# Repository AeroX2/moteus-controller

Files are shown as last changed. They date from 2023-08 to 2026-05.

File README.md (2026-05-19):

# moteus-controller

A custom servo BLDC driver loosely based on the [mjbots Moteus r4.11](https://github.com/mjbots/moteus/tree/main/hw/controller/r4.11) hardware.

Main differences from upstream Moteus r4.11:

- **STSPIN32G4** integrated gate driver + STM32G431 instead of separate DRV8353S and MCU.
- Schematic and BOM trimmed/substituted for **JLCPCB** assembly.
- **AS5048A** magnetic encoder.
- **MAX3051** CAN transceiver.
- Firmware built on **SimpleFOC** + Arduino-stm32duino instead of the mjbots firmware.

## Repository layout

```
moteus-controller/
├── pcb/                # KiCad schematic + PCB
├── firmware/           # SimpleFOC-based motor controller firmware (PlatformIO + Arduino)
├── bootloader/         # OpenBLT bootloader for STM32G431VB  (submodule -> AeroX2/OpenBLT-STM32)
└── openblt/            # OpenBLT library + mjbots fdcanusb driver (submodule -> AeroX2/openblt)
```

`firmware/`, `bootloader/`, and `openblt/` each have their own build setup and README.

## Quick build / flash

Prerequisites: [PlatformIO Core](https://platformio.org/install/cli), an ST-Link, optionally a [mjbots fdcanusb](https://github.com/mjbots/fdcanusb) for CAN-FD uploads.

Clone with submodules:

```bash
git clone --recurse-submodules https://github.com/AeroX2/moteus-controller.git
cd moteus-controller
```

Flash the bootloader once (writes at `0x08000000`, ~8 KB):

```bash
pio run -d bootloader -e moteus_g431 -t upload
```

Flash the application (writes at `0x08005000`):

```bash
pio run -d firmware -e moteus -t upload
```

Power-cycle the board; the bootloader runs for ~3 s, then jumps to the app.

After the bootloader is in place, subsequent firmware uploads can go over CAN-FD via fdcanusb (no ST-Link needed):

```bash
pio run -d firmware -e moteus_openblt_can -t upload
```

## Bootloader

`bootloader/` is a bare-metal **stm32cube + PlatformIO** port of the upstream [Feaser OpenBLT](https://github.com/feaser/openblt) Nucleo-G431 demo, adapted for the moteus-controller hardware:

- HSI → PLL → 170 MHz (no HSE crystal on this board).
- FDCAN1 routed to PA11/PA12 (vs Nucleo's PB8/PB9).
- 20 KB reserved at `0x08000000`; app starts at `0x08005000`; the final 2 KB flash page (`0x0801F800`) is reserved for application PID storage and never touched by the bootloader.

OpenBLT library + STM32G4 port sources are compiled directly from the `openblt/` submodule by `bootloader/src/build.py` — there are no local copies of those files in `bootloader/`, so updating to a newer OpenBLT is just a submodule bump.

## CAN-FD upload (`moteus_openblt_can` env)

The CAN-FD upload path uses a custom **mjbots fdcanusb** host driver added to LibOpenBLT (see `openblt/Host/Source/LibOpenBLT/port/windows/canif/fdcanusb/`) plus a small wrapper (`firmware/host_openblt_flash/`) and a Python harness (`firmware/scripts/openblt_host_upload.py`) that handles pre-reset, device discovery, and srec conversion.

Build the host tool once:

```bash
python firmware/scripts/build_host_openblt_flash.py
```

Then `pio run -d firmware -e moteus_openblt_can -t upload` does the rest.

Tuning knobs live in `firmware/platformio.ini` under `[env:moteus_openblt_can]`:

- `custom_openblt_can_device` — fdcanusb COM port and USB baud.
- `custom_openblt_can_tid` / `custom_openblt_can_rid` — XCP CAN IDs (default `667` / `7E1`, must match `bootloader/src/blt_conf.h`).
- `custom_openblt_reset_discover` / `custom_openblt_reset_target_id` — control how the running application is asked to reboot into the bootloader before uploading.

## License

The original mjbots Moteus design is licensed under Apache 2.0; see `LICENSE`. OpenBLT and its derivatives are GPLv3 (see `openblt/Doc/license.html`).

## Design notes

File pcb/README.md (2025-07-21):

# moteus-controller

## Schematic
schematic

## PCB
https://kicanvas.org/?github=https%3A%2F%2Fgithub.com%2FAeroX2%2Fmoteus-controller%2Ftree%2Fmain%2Fpcb

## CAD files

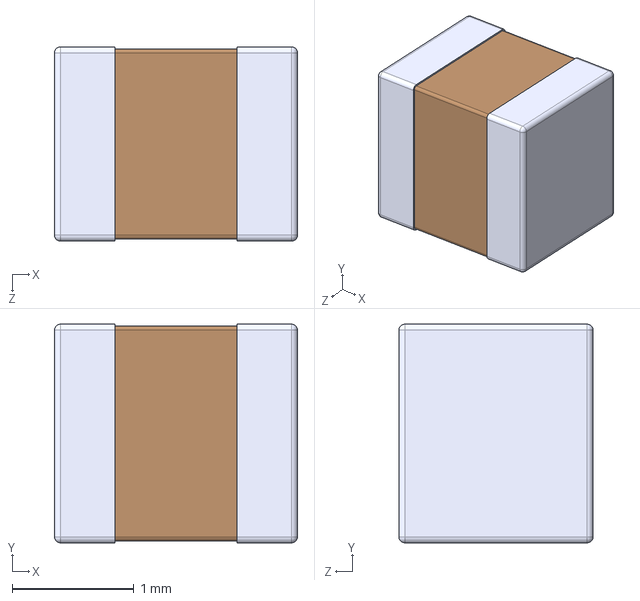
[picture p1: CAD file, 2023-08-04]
pcb/LBM2016T120J.step
2.00 x 1.80 x 1.60 mm

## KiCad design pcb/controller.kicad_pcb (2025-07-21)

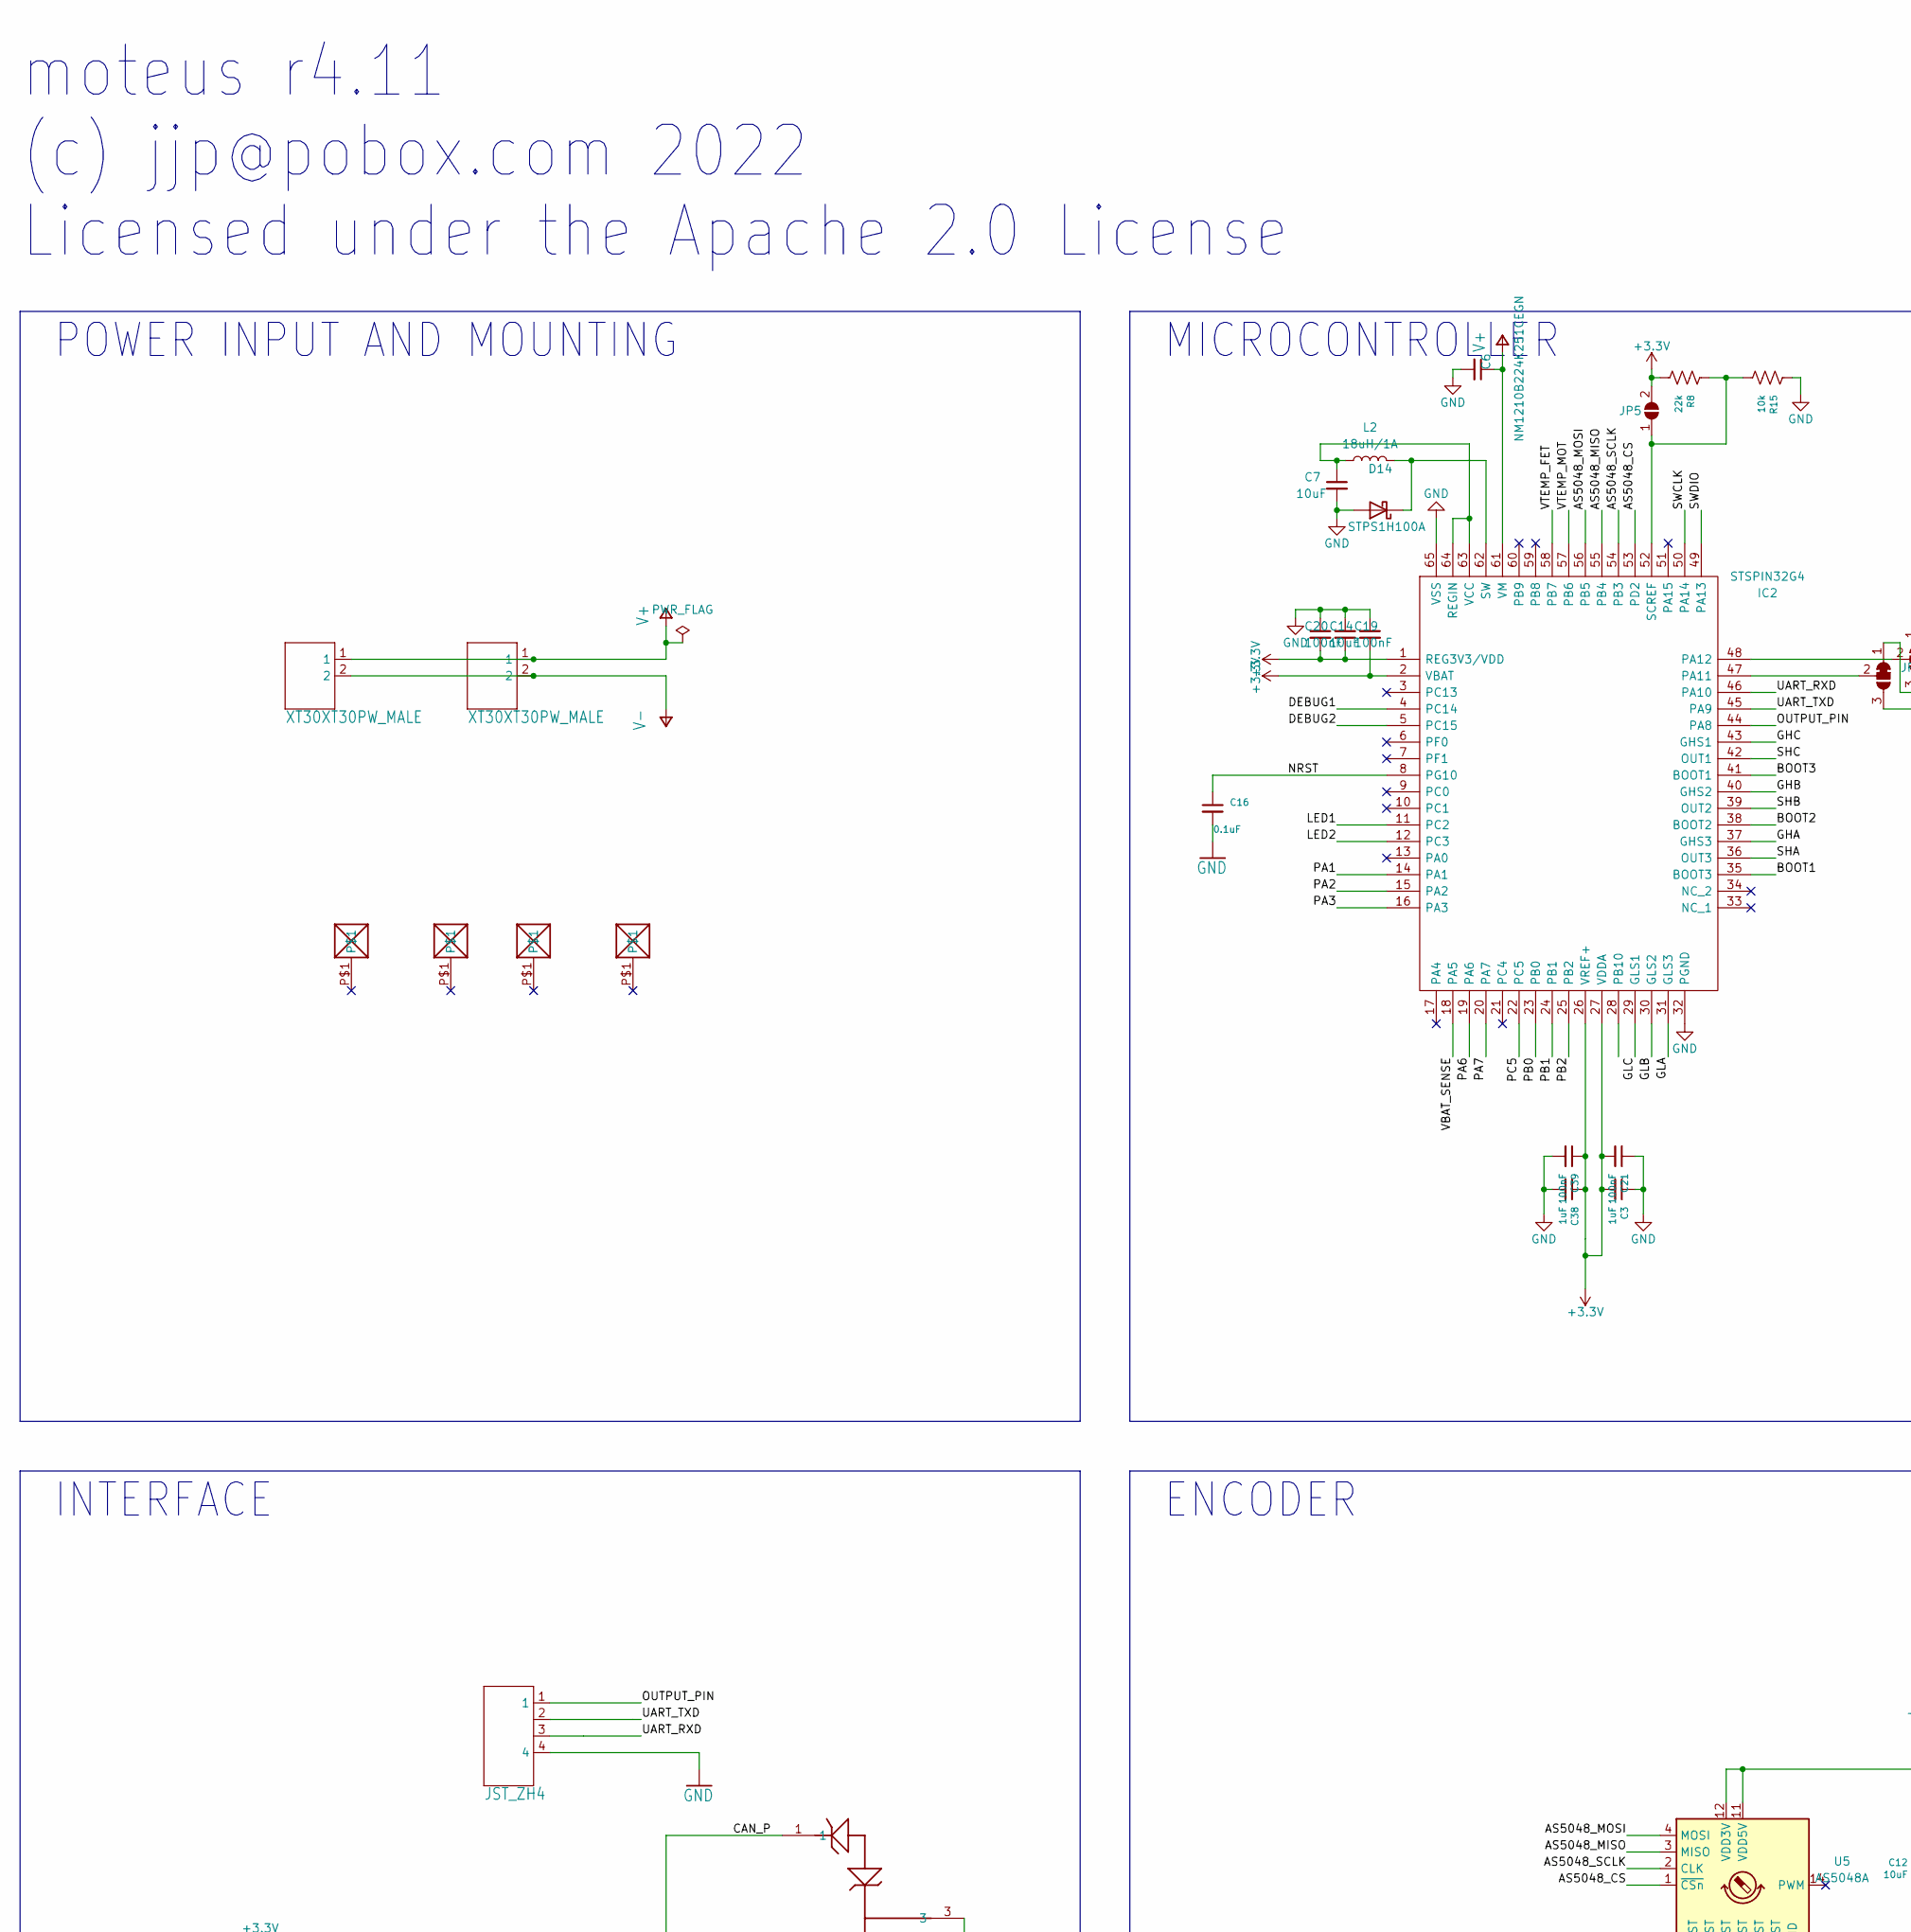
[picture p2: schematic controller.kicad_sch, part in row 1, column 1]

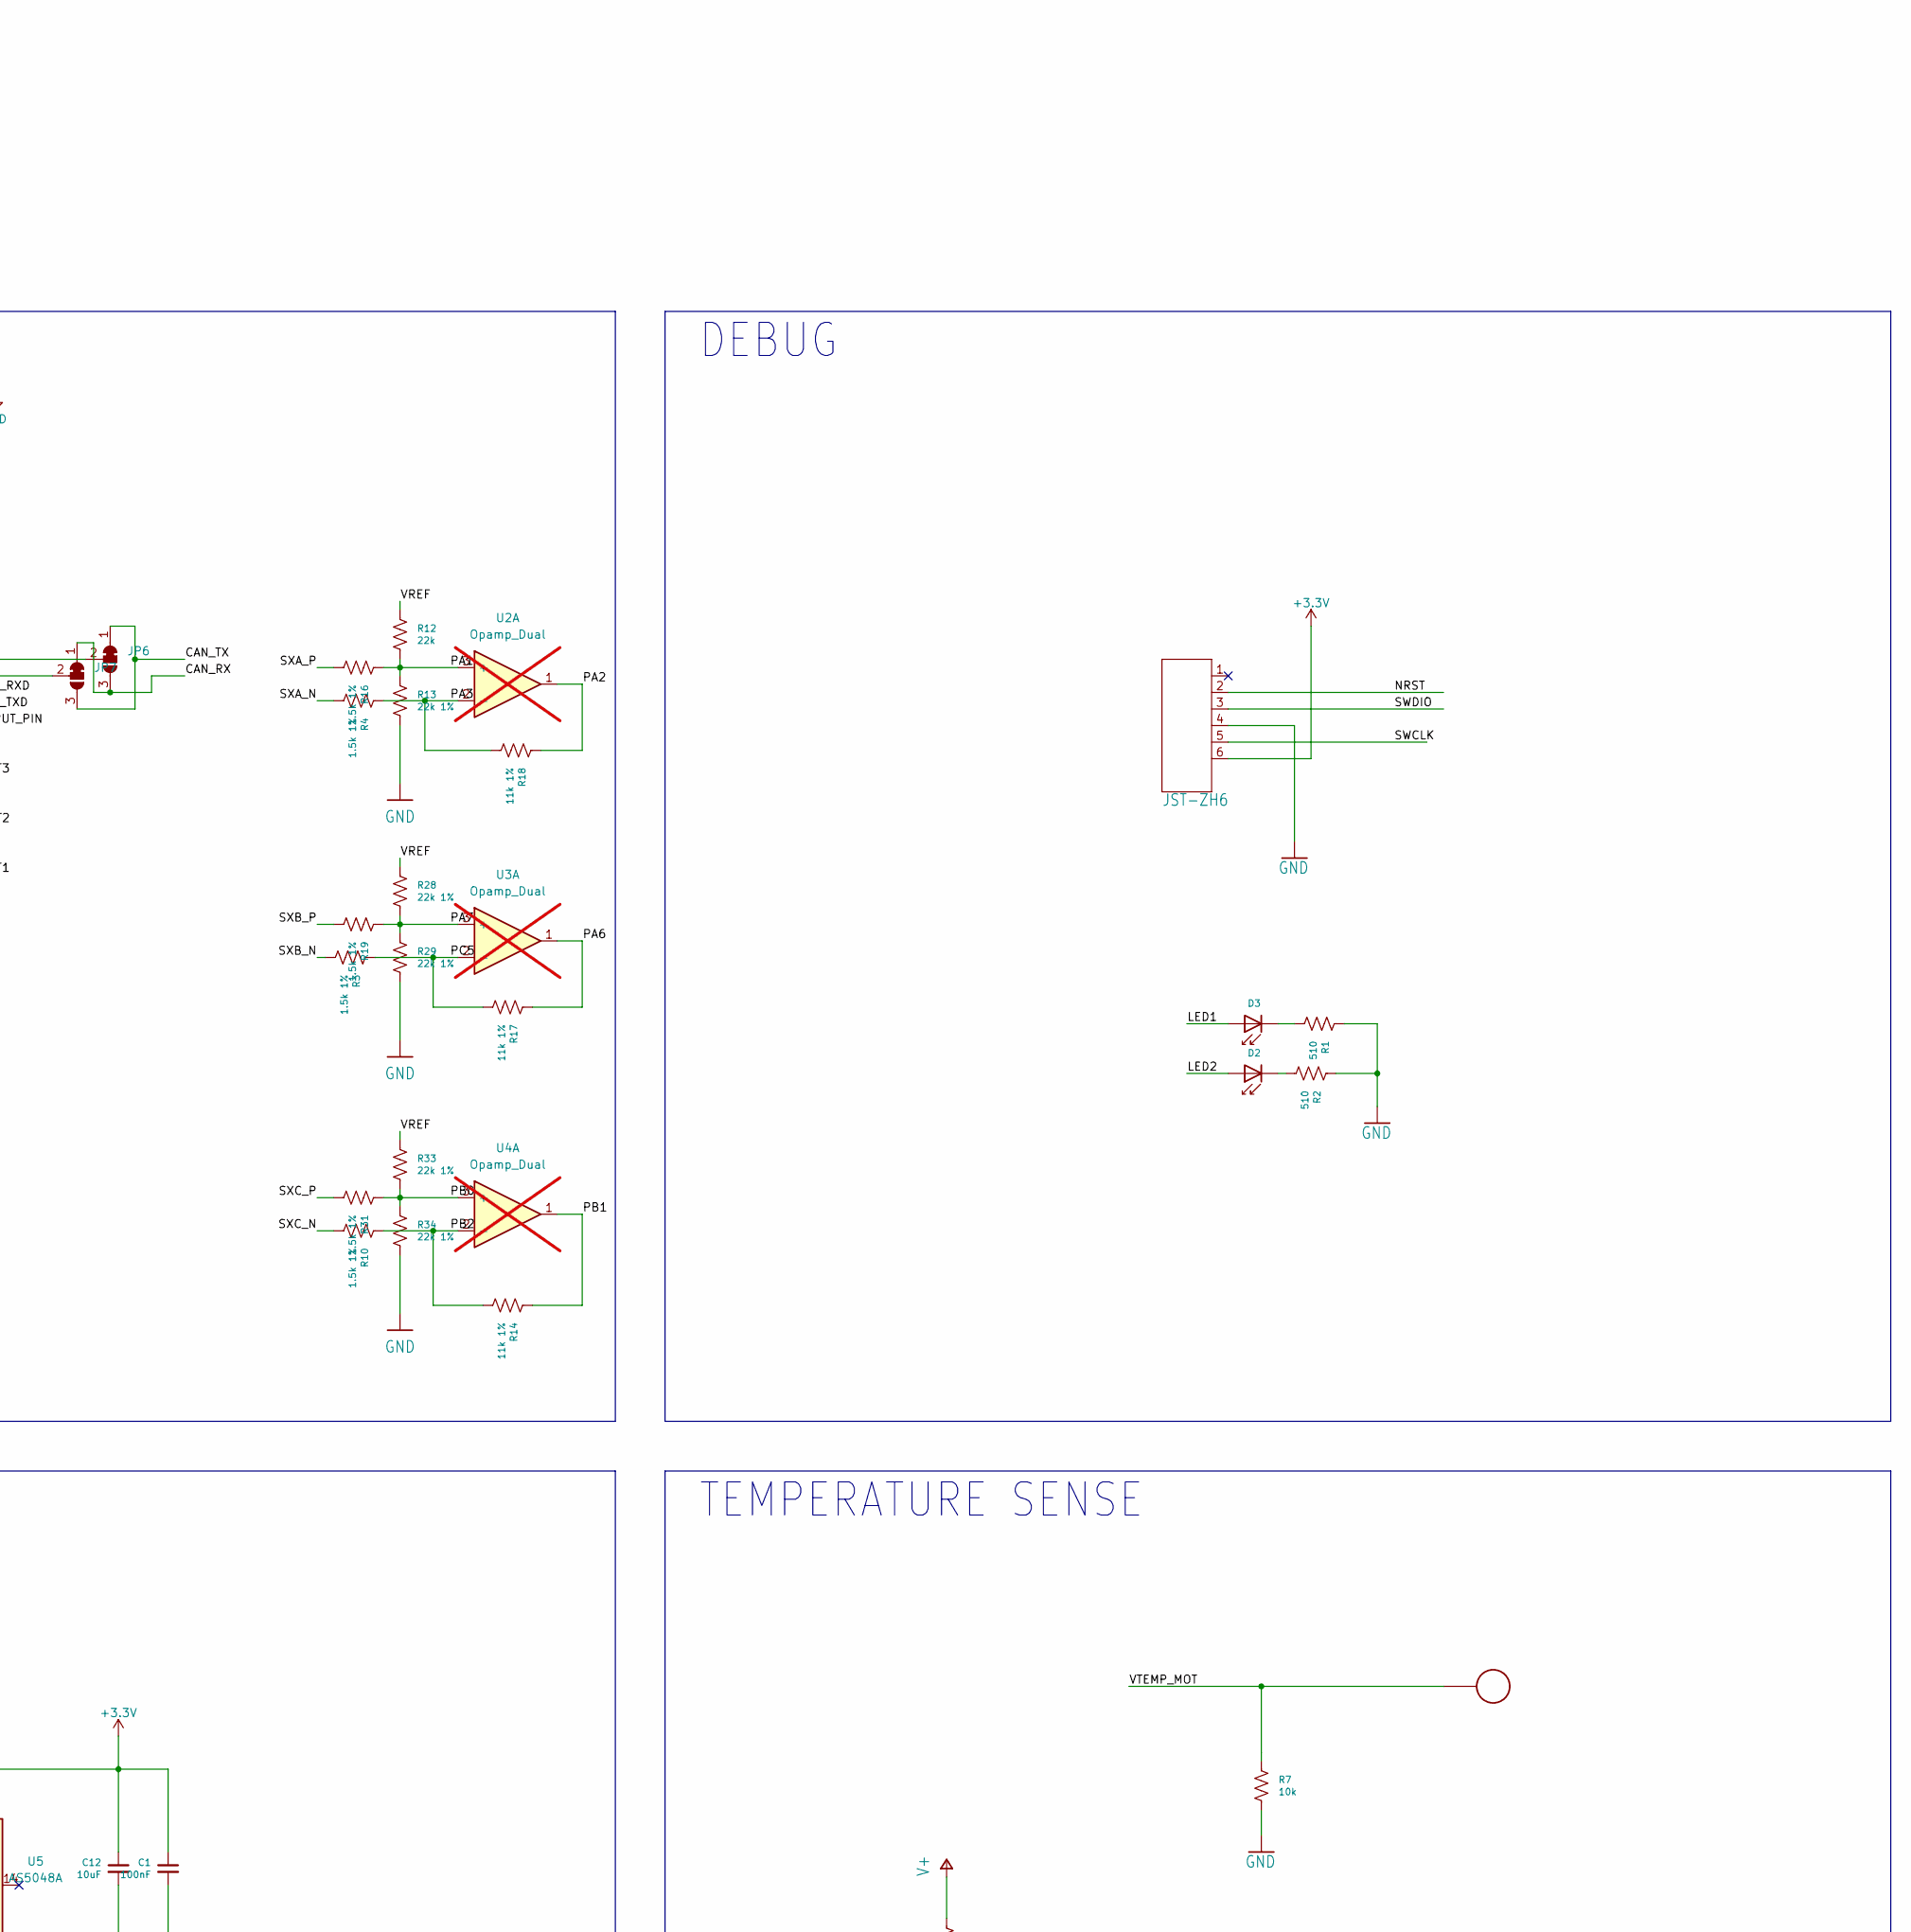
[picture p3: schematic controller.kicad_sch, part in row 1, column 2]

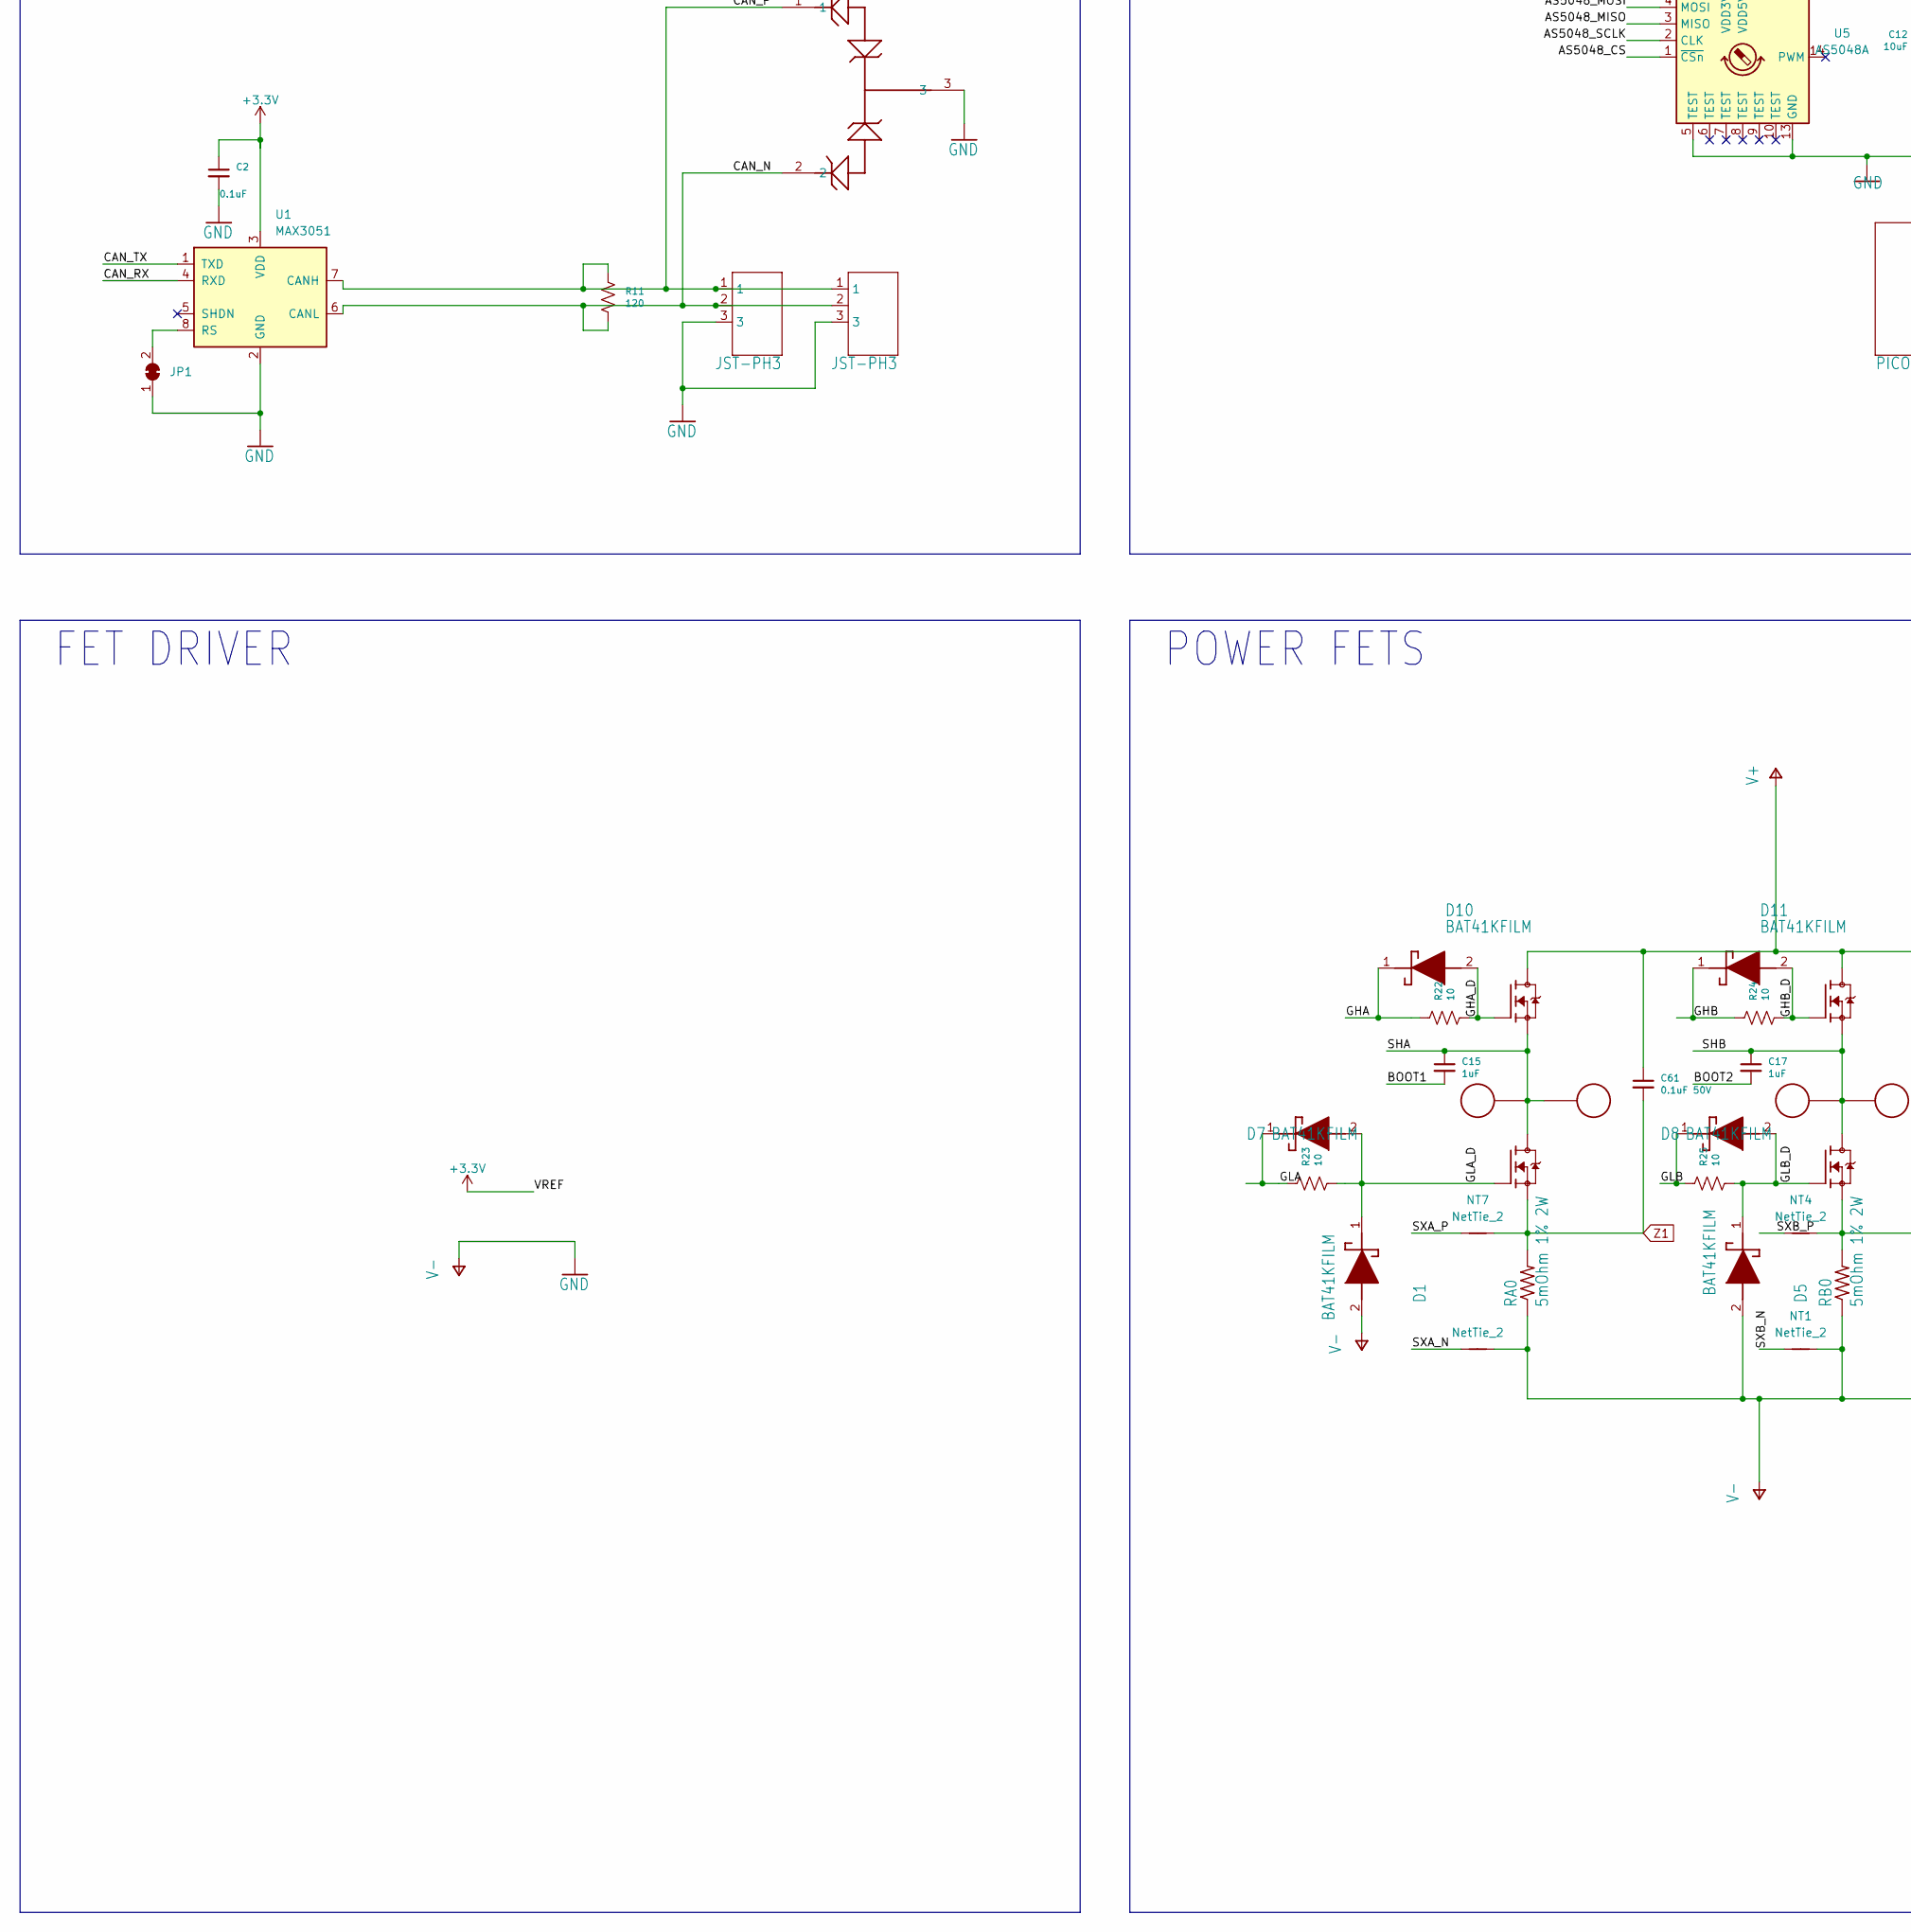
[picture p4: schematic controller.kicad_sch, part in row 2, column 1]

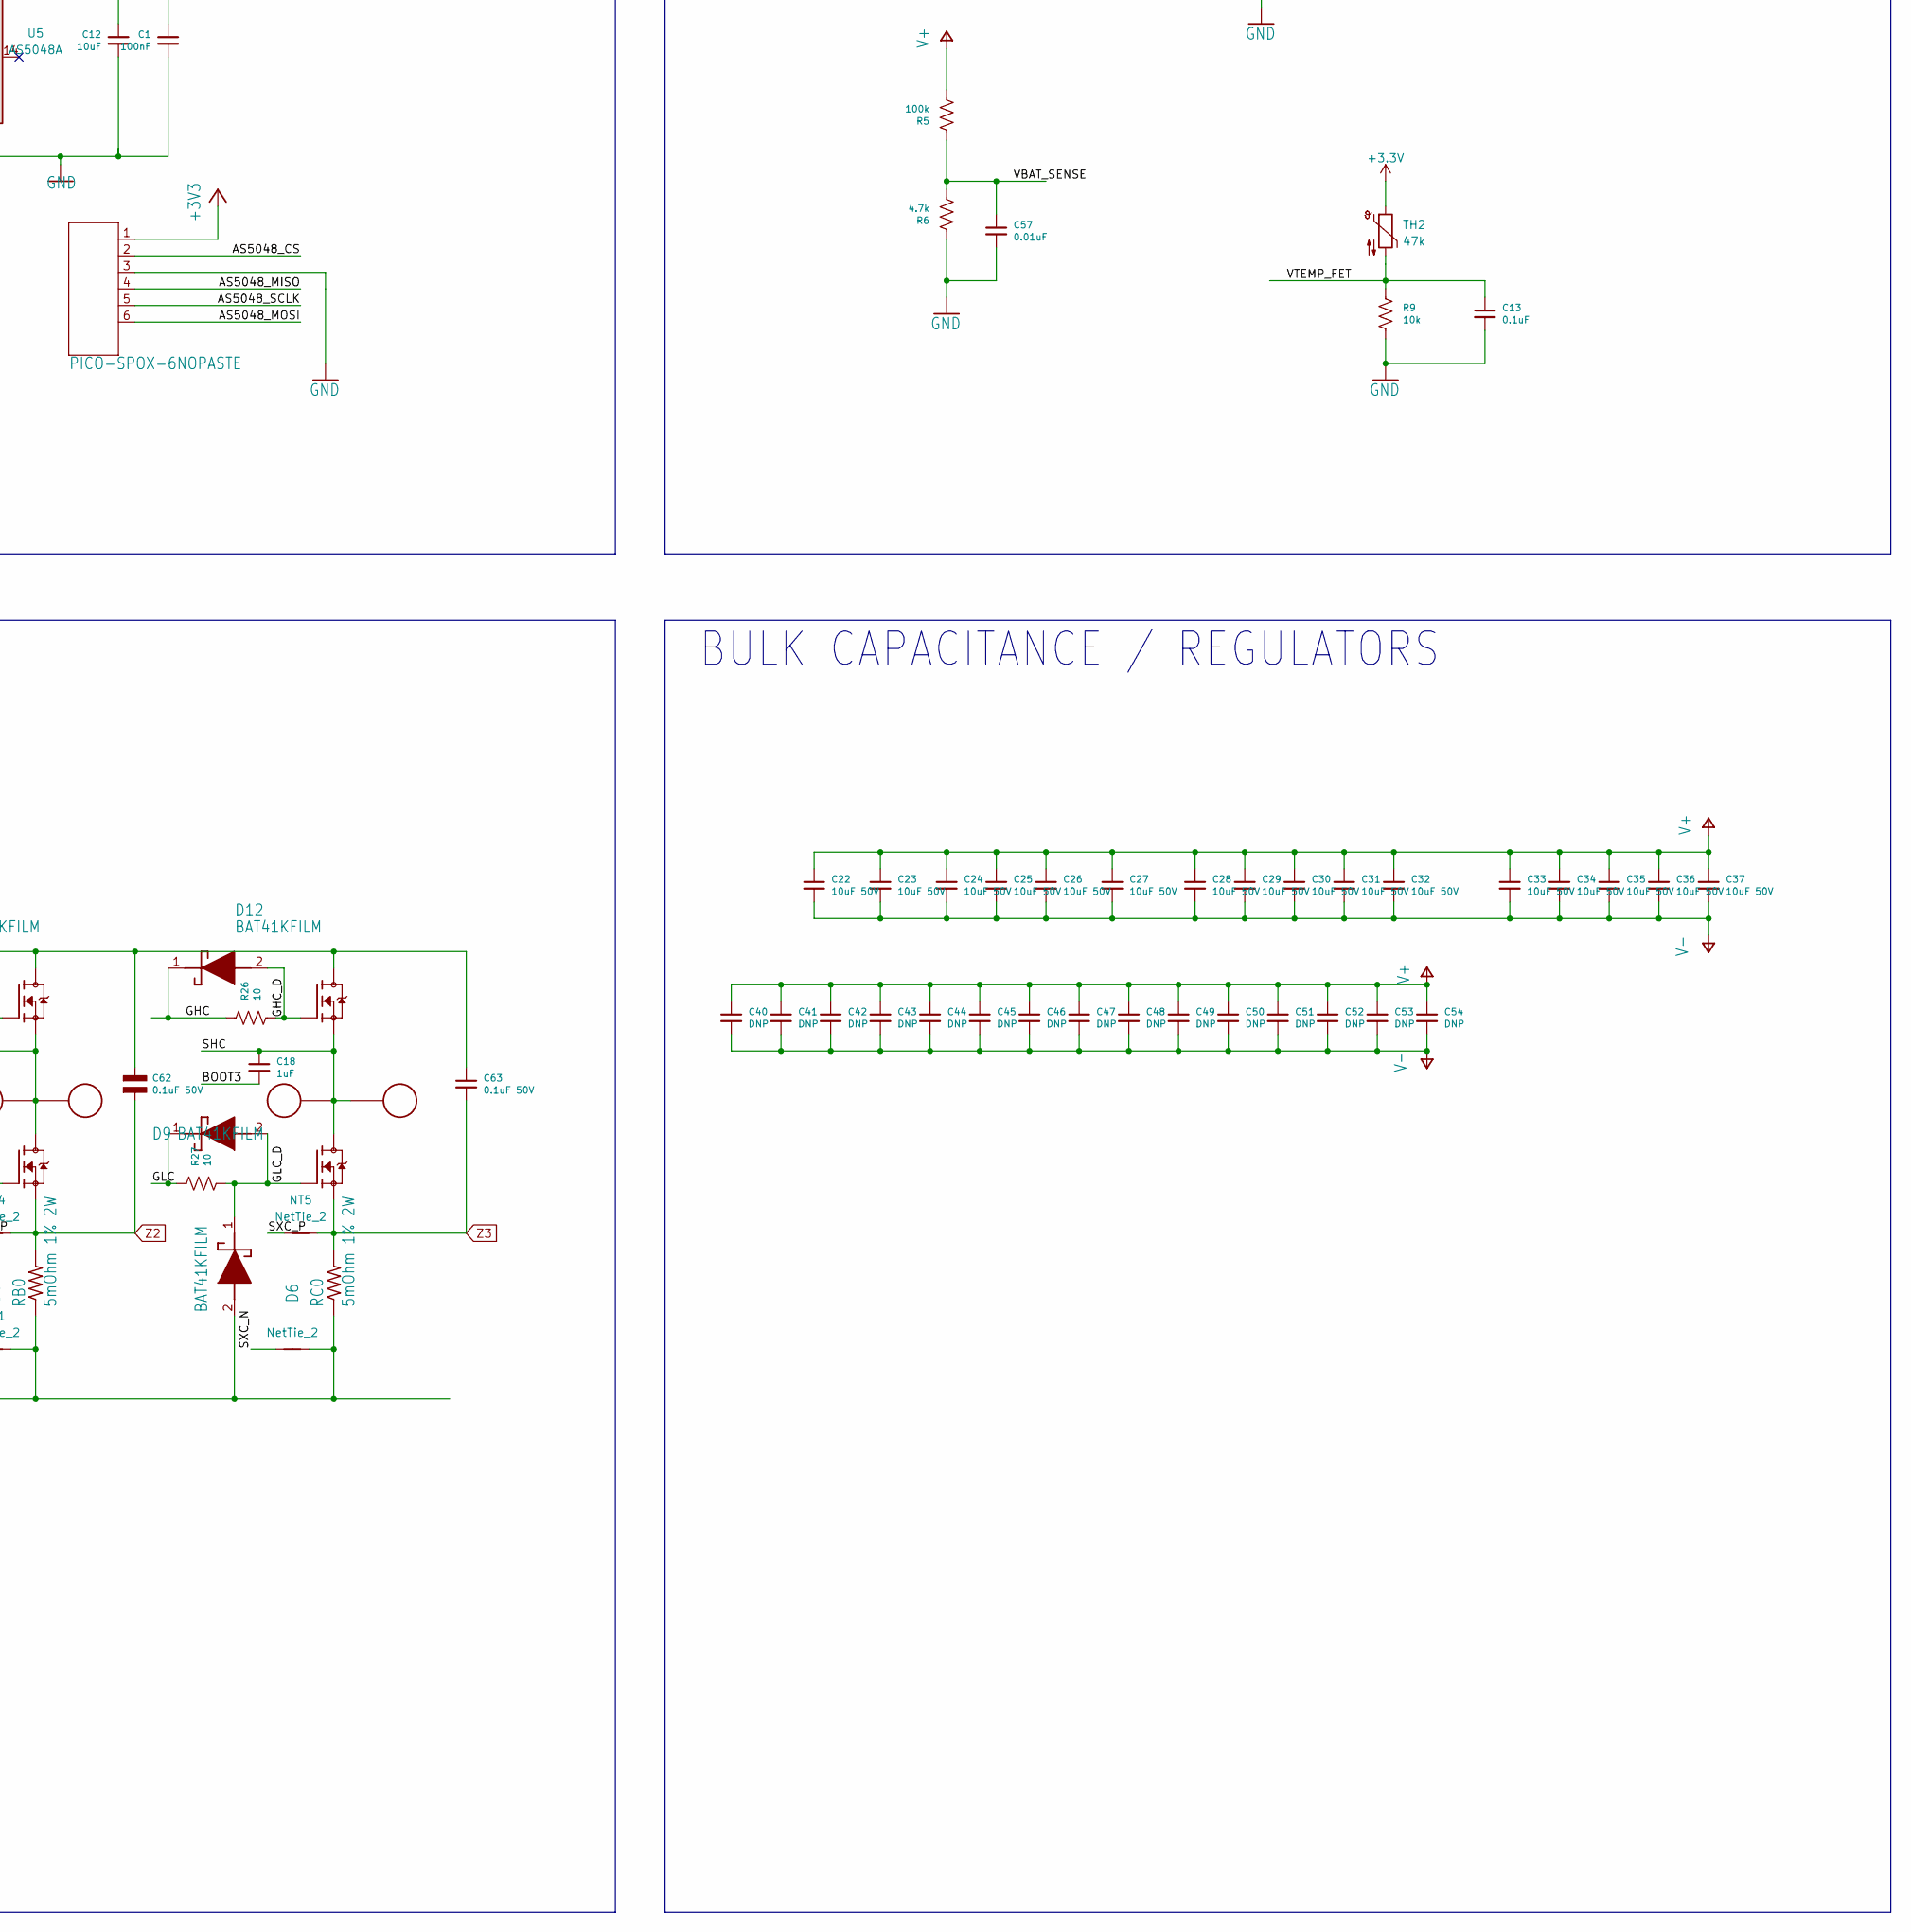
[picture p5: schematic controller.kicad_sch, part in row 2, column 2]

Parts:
A0: PAD16AWG_PAD; 16AWG_PAD
ABS0: JST_ZH4; JST_S4B-ZR-SM4A-TF(LF)(SN); MPN S4B-ZR-SM4A-TF(LF)(SN)
B0: PAD16AWG_PAD; 16AWG_PAD
C0: PAD16AWG_PAD; 16AWG_PAD
C1: 100nF; C_0402_1005Metric; MPN MF-CAP-0402-0.1uF
C2, C13, C16: 0.1uF; C_0402_1005Metric; MPN MF-CAP-0402-0.1uF
C3, C15, C17, C18, C38: 1uF; C_0402_1005Metric; MPN MF-CAP-0402-1uF
C6: NM1210B224K251CEGN; C_1210_3225Metric
C7, C14: 10uF; C_0402_1005Metric
C12: 10uF; C_0402_1005Metric; MPN MF-CAP-0402-0.1uF
C19, C20: 100nF; C_0402_1005Metric
C21, C39: 100nF; C_0402_1005Metric; MPN MF-CAP-0402-1uF
C22, C23, C24, C25, C26, C27, C28, C29, C30, C31, C32, C33, C34, C35, C36, C37: 10uF 50V; C_1206_3216Metric; MPN C3216X7R1H106K160AE
C40, C41, C42, C43, C44, C45, C46, C47, C48, C49, C50, C51, C52, C53, C54: DNP; C_1206_3216Metric
C57: 0.01uF; C_0402_1005Metric; MPN MF-CAP-0402-0.01uF
C61, C63: 0.1uF 50V; C_1206_3216Metric; MPN 12065C104KAZ2A
C62: 0.1uF 50V; C0603_NOBORDER; MPN 06035C104KAZ2A
CAN1, CAN2: JST-PH3; JST_S3B-PH-SM4-TB(LF)(SN); MPN S3B-PH-SM4-TB(LF)(SN)
D1, D5, D6, D7, D8, D9, D10, D11, D12: BAT41KFILM; SODFL1608X70N; MPN BAT41KFILM
D2: MF-LED-0603-RED; LED_0603_1608Metric; MPN MF-LED-0603-GREEN
D3: MF-LED-0603-RED; LED_0603_1608Metric
D4: DUAL_TVS; SOT23-3; MPN CDSOT23-0502B
D14: STPS1H100A; D_SMA
DA0: PAD24AWG_PAD; 24AWG_PAD
DB0: PAD24AWG_PAD; 24AWG_PAD
DC0: PAD24AWG_PAD; 24AWG_PAD
ENC0: PICO-SPOX-6NOPASTE; PICO-SPOX-SMT-RA-6-NOPASTE
IC2: STSPIN32G4; QFN50P900X900X100-65N-D; Manufacturer_Part_Number STSPIN32G4; Mouser Part Number 511-STSPIN32G4
J1, J2: XT30XT30PW_MALE; XT30PW_MALE
JP1: SolderJumper_2_Bridged; SolderJumper-2_P1.3mm_Bridged_Pad1.0x1.5mm
JP5: SolderJumper_2_Open; SolderJumper-2_P1.3mm_Open_RoundedPad1.0x1.5mm
JP6, JP7: SolderJumper_3_Bridged12; SolderJumper-3_P1.3mm_Bridged12_RoundedPad1.0x1.5mm
L2: 18uH/1A; IND-SMD_L5.8-W5.2_SCD0503T
M1, M2, M3, M4: MOUNT; MountingHole_3.2mm_M3_DIN965_Pad
NT1, NT4, NT5, NT6, NT7, NT8: NetTie_2; NetTie-2_SMD_Pad0.2mm
Q1, Q3, Q5: TPH1R204PLSOP_ADVANCE_8; SOP_ADVANCE_8; MPN TPH2R506PL,L1Q
Q2, Q4, Q6: TPH1R204PLSOP_ADVANCE_8; SOP_ADVANCE_8; MPN TPH4R50ANH,L1Q(M
R1, R2: 510; R_0402_1005Metric; MPN MF-RES-0402-560
R3, R4, R10, R16, R19, R31: 1.5k 1%; R_0402_1005Metric; MPN MF-RES-0402-2K
R5: 100k; R_0402_1005Metric; MPN RC0402FR-07100KL
R6: 4.7k; R_0402_1005Metric; MPN RC0402FR-074K7L
R7, R9: 10k; R_0402_1005Metric; MPN RC0402FR-0710KL
R8, R12: 22k; R_0402_1005Metric; MPN MF-RES-0402-2K
R11: 120; R_0402_1005Metric; MPN MF-RES-0402-2K
R13, R28, R29, R33, R34: 22k 1%; R_0402_1005Metric; MPN MF-RES-0402-2K
R14, R17, R18: 11k 1%; R_0402_1005Metric; MPN MF-RES-0402-2K
R15: 10k; R_0402_1005Metric; MPN MF-RES-0402-2K
R22, R23, R24, R25, R26, R27: 10; R_0402_1005Metric; MPN RC0402FR-077R5L
RA0: 5mOhm 1% 2W; R_1206_3216Metric; MPN HCS1206FTL500
RB0: 5mOhm 1% 2W; R_1206_3216Metric; MPN HCS1206FTL500
RC0: 5mOhm 1% 2W; R_1206_3216Metric; MPN HCS1206FTL500
SWD0: JST-ZH6; JST_S6B-ZR-SM4A-TF(LF)(SN); MPN S6B-ZR-SM4A-TF(LF)(SN)
TEMP2: PAD24AWG_PAD; 24AWG_PAD
TH2: 47k; R_0603_1608Metric
U1: MAX3051; TSOT-23-8
U2, U3, U4: Opamp_Dual; not fitted
U5: AS5048A; TSSOP-14_4.4x5mm_P0.65mm

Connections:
+3.3V: C1.1, C2.1, C3.2, C12.1, C14.2, C19.2, C20.2, C21.2, C38.1, C39.1, IC2.1 (REG3V3/VDD), IC2.2 (VBAT), IC2.26 (VREF+), IC2.27 (VDDA), JP5.2 (B), R8.2, R12.1, R28.1, R33.1, SWD0.6, TH2.1, U1.3 (VDD), U5.11 (VDD5V), U5.12 (VDD3V)
+3V3: ENC0.1
/AS5048_CS: ENC0.2, IC2.53 (PD2), U5.1 (~CSn)
/AS5048_MISO: ENC0.4, IC2.55 (PB4), U5.3 (MISO)
/AS5048_MOSI: ENC0.6, IC2.56 (PB5), U5.4 (MOSI)
/AS5048_SCLK: ENC0.5, IC2.54 (PB3), U5.2 (CLK)
/BOOT1: C15.2, IC2.35 (BOOT3)
/BOOT2: C17.2, IC2.38 (BOOT2)
/BOOT3: C18.2, IC2.41 (BOOT1)
/CAN_N: CAN1.2, CAN2.2, D4.2, R11.2, U1.6 (CANL)
/CAN_P: CAN1.1, CAN2.1, D4.1, R11.1, U1.7 (CANH)
/CAN_RX: JP6.3 (B), JP7.1 (A), U1.4 (RXD)
/CAN_TX: JP6.1 (A), JP7.3 (B), U1.1 (TXD)
/DEBUG1: IC2.4 (PC14)
/DEBUG2: IC2.5 (PC15)
/GHA: D10.1 (K), IC2.37 (GHS3), R22.1
/GHA_D: D10.2 (A), Q1.4 (G), R22.2
/GHB: D11.1 (K), IC2.40 (GHS2), R24.1
/GHB_D: D11.2 (A), Q3.4 (G), R24.2
/GHC: D12.1 (K), IC2.43 (GHS1), R26.1
/GHC_D: D12.2 (A), Q5.4 (G), R26.2
/GLA: D7.1 (K), IC2.31 (GLS3), R23.1
/GLA_D: D1.1 (K), D7.2 (A), Q2.4 (G), R23.2
/GLB: D8.1 (K), IC2.30 (GLS2), R25.1
/GLB_D: D5.1 (K), D8.2 (A), Q4.4 (G), R25.2
/GLC: D9.1 (K), IC2.29 (GLS1), R27.1
/GLC_D: D6.1 (K), D9.2 (A), Q6.4 (G), R27.2
/LED1: D3.2 (A), IC2.11 (PC2)
/LED2: D2.2 (A), IC2.12 (PC3)
/NRST: C16.1, IC2.8 (PG10), SWD0.2
/OUTPUT_PIN: ABS0.1, IC2.44 (PA8)
/PA1: IC2.14 (PA1), R12.2, R13.1, R16.1, U2.3 (+)
/PA2: IC2.15 (PA2), R18.1, U2.1
/PA3: IC2.16 (PA3), R4.1, R18.2, U2.2 (-)
/PA6: IC2.19 (PA6), R17.1, U3.1
/PA7: IC2.20 (PA7), R19.1, R28.2, R29.1, U3.3 (+)
/PB0: IC2.23 (PB0), R31.1, R33.2, R34.1, U4.3 (+)
/PB1: IC2.24 (PB1), R14.1, U4.1
/PB2: IC2.25 (PB2), R10.1, R14.2, U4.2 (-)
/PC5: IC2.22 (PC5), R3.1, R17.2, U3.2 (-)
/SHA: A0.1, C15.1, DA0.P$1, IC2.36 (OUT3), Q1.1 (S), Q1.2 (S), Q1.3 (S), Q2.5 (D), Q2.6 (D), Q2.7 (D), Q2.8 (D), Q2.PAD (D)
/SHB: B0.1, C17.1, DB0.P$1, IC2.39 (OUT2), Q3.1 (S), Q3.2 (S), Q3.3 (S), Q4.5 (D), Q4.6 (D), Q4.7 (D), Q4.8 (D), Q4.PAD (D)
/SHC: C0.1, C18.1, DC0.P$1, IC2.42 (OUT1), Q5.1 (S), Q5.2 (S), Q5.3 (S), Q6.5 (D), Q6.6 (D), Q6.7 (D), Q6.8 (D), Q6.PAD (D)
/SWCLK: IC2.50 (PA14), SWD0.5
/SWDIO: IC2.49 (PA13), SWD0.3
/SXA_N: NT8.1, R4.2
/SXA_P: NT7.1, R16.2
/SXB_N: NT1.1, R3.2
/SXB_P: NT4.1, R19.2
/SXC_N: NT6.1, R10.2
/SXC_P: NT5.1, R31.2
/UART_RXD: ABS0.3, IC2.46 (PA10)
/UART_TXD: ABS0.2, IC2.45 (PA9)
/VBAT_SENSE: C57.1, IC2.18 (PA5), R5.1, R6.2
/VTEMP_FET: C13.1, IC2.58 (PB7), R9.1, TH2.2
/VTEMP_MOT: IC2.57 (PB6), R7.1, TEMP2.P$1
GND: ABS0.4, C1.2, C2.2, C3.1, C6.2, C7.2, C12.2, C13.2, C14.1, C16.2, C19.1, C20.1, C21.1, C22.2, C23.2, C24.2, C25.2, C26.2, C27.2, C28.2, C29.2, C30.2, C31.2, C32.2, C33.2, C34.2, C35.2, C36.2, C37.2, C38.2, C39.2, C40.2, C41.2, C42.2, C43.2, C44.2, C45.2, C46.2, C47.2, C48.2, C49.2, C50.2, C51.2, C52.2, C53.2, C54.2, C57.2, CAN1.3, CAN2.3, D1.2 (A), D4.3, D5.2 (A), D6.2 (A), D14.2 (A), ENC0.3, IC2.32 (PGND), IC2.65 (VSS), J1.2, J2.2, JP1.1 (A), NT1.2, NT6.2, NT8.2, R1.1, R2.1, R6.1, R7.2, R9.2, R13.2, R15.1, R29.2, R34.2, RA0.1, RB0.1, RC0.1, SWD0.4, U1.2 (GND), U5.5 (TEST), U5.13 (GND)
unnamed: D2.1 (K), R2.2
unnamed: D3.1 (K), R1.2
unnamed: D14.1 (K), IC2.62 (SW), L2.2
unnamed: IC2.47 (PA11), JP7.2 (C)
unnamed: IC2.48 (PA12), JP6.2 (C)
unnamed: C7.1, IC2.63 (VCC), IC2.64 (REGIN), L2.1
unnamed: IC2.52 (SCREF), JP5.1 (A), R8.1, R15.2
unnamed: JP1.2 (B), U1.8 (RS)
V+: C6.1, C22.1, C23.1, C24.1, C25.1, C26.1, C27.1, C28.1, C29.1, C30.1, C31.1, C32.1, C33.1, C34.1, C35.1, C36.1, C37.1, C40.1, C41.1, C42.1, C43.1, C44.1, C45.1, C46.1, C47.1, C48.1, C49.1, C50.1, C51.1, C52.1, C53.1, C54.1, C61.1, C62.P$1, C63.1, IC2.61 (VM), J1.1, J2.1, Q1.5 (D), Q1.6 (D), Q1.7 (D), Q1.8 (D), Q1.PAD (D), Q3.5 (D), Q3.6 (D), Q3.7 (D), Q3.8 (D), Q3.PAD (D), Q5.5 (D), Q5.6 (D), Q5.7 (D), Q5.8 (D), Q5.PAD (D), R5.2
Z1: C61.2, NT7.2, Q2.1 (S), Q2.2 (S), Q2.3 (S), RA0.2
Z2: C62.P$2, NT4.2, Q4.1 (S), Q4.2 (S), Q4.3 (S), RB0.2
Z3: C63.2, NT5.2, Q6.1 (S), Q6.2 (S), Q6.3 (S), RC0.2

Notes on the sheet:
DEBUG
POWER FETS
moteus r4.11 (c) jjp@pobox.com 2022 Licensed under the Apache 2.0 License
ENCODER
BULK CAPACITANCE / REGULATORS
INTERFACE
MICROCONTROLLER
FET DRIVER
TEMPERATURE SENSE
POWER INPUT AND MOUNTING

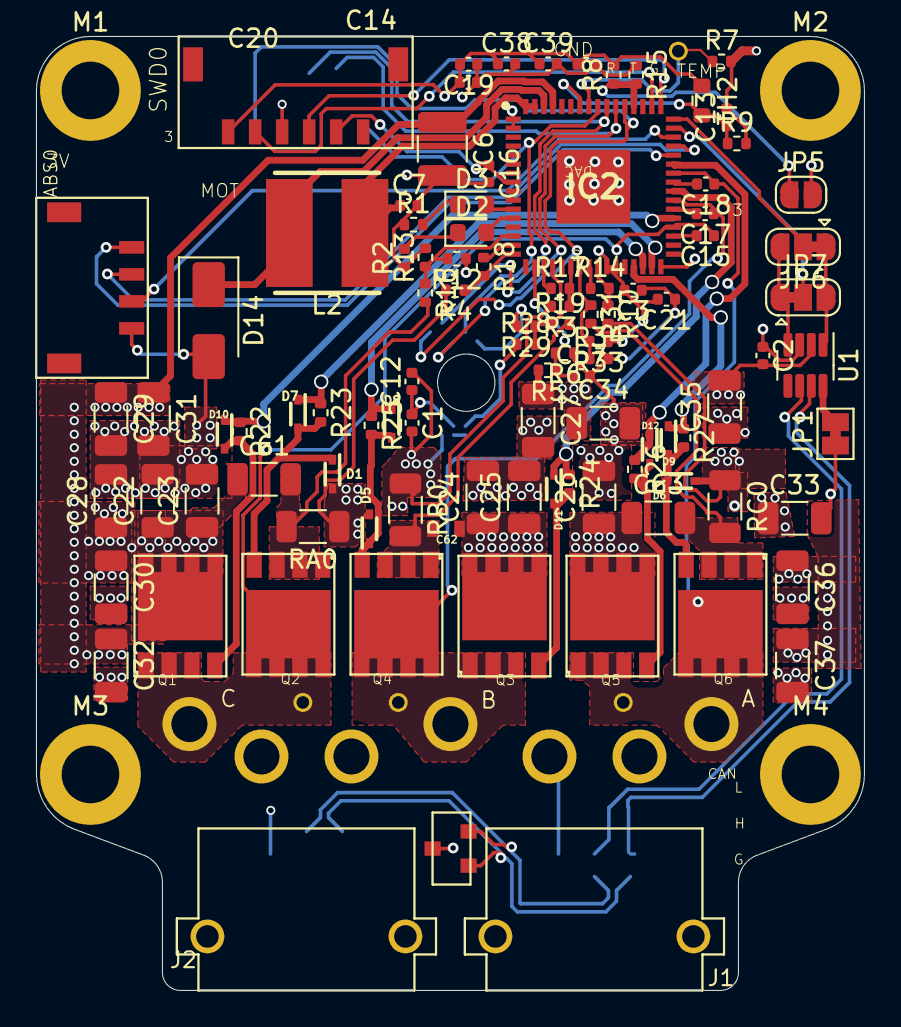
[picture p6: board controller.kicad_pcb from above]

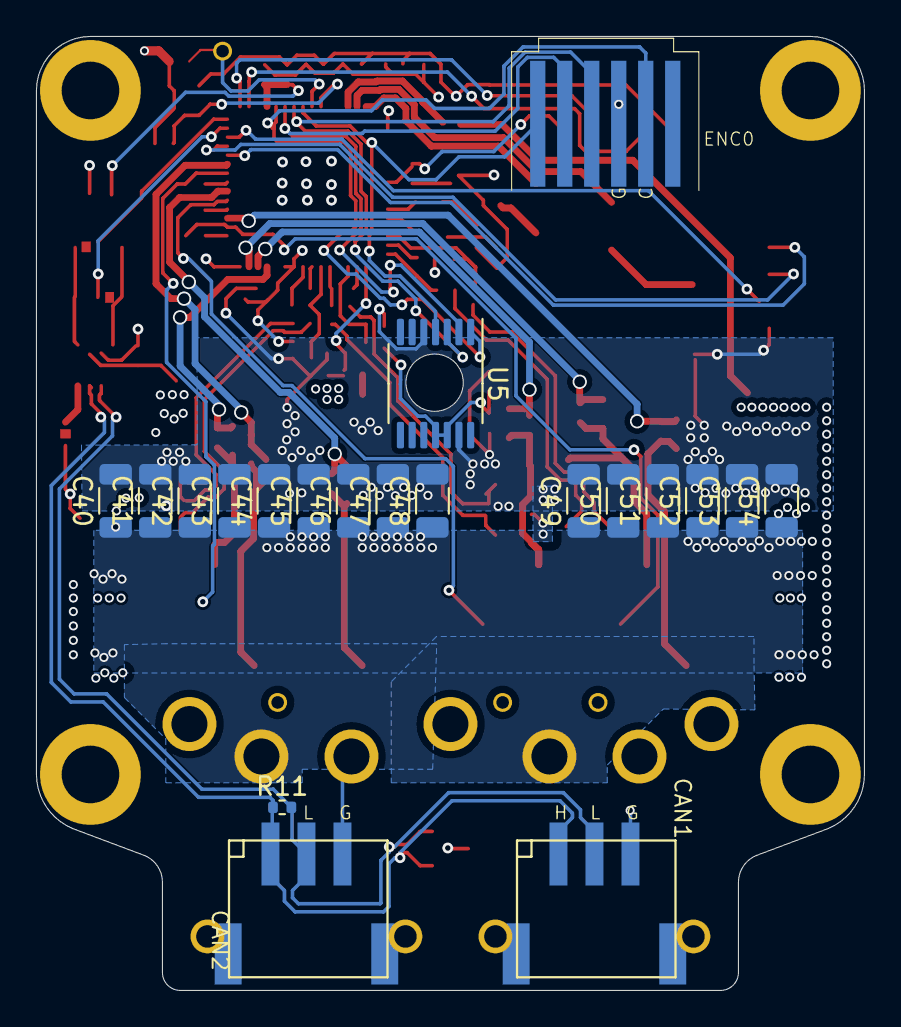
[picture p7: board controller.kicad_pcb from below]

Board: 4 copper layers, 46.0 x 53.0 mm, 137 parts (20 on the bottom side), 66 nets.

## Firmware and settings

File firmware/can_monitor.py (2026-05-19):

#!/usr/bin/env python3
"""
CAN Monitor and Command Script with Rich TUI
Connects to COM5 at 115200 baud to monitor CAN FD messages and send commands
"""

import math
import os
import serial
import threading
import time
import struct
import sys
import select
from collections import deque
from datetime import datetime

from rich.console import Console
from rich.live import Live
from rich.panel import Panel
from rich.text import Text
from rich.layout import Layout
from rich import box

# Motion: firmware sends angle [rad], velocity [rad/s] (MCU vel is instantaneous/noisy — not used for display).
# Velocity: only from unwrapped angle slope over a time window (never from packet velocity field).
_VELOCITY_WINDOW_S = 1.0  # seconds of history for slope (longer = smoother, slower to respond)
# Full-window slope only if oldest→newest span ≥ this (else use last pair of samples — needed for ~10 Hz telemetry).
_VELOCITY_MIN_DT_S = 0.08
_VELOCITY_EMA_ALPHA = 0.18  # low-pass on window slope (smaller = smoother rad/s)
_ANGLE_HISTORY_MAXLEN = 80
_MOTION_GAP_RESET_S = 1.5  # reset estimator if telemetry gaps (e.g. disconnect)

# Windows-compatible getch implementation
def getch():
    try:
        import msvcrt
        if msvcrt.kbhit():
            char = msvcrt.getch()
            if char == b'\r':  # Enter key
                return '\r'
            elif char == b'\x08':  # Backspace
                return '\b'
            elif char == b'\x03':  # Ctrl+C
                return '\x03'
            elif char == b'\t':  # Tab key
                return '\t'
            elif char == b'\xe0':  # Arrow key prefix
                # Read the next byte to determine which arrow key
                next_char = msvcrt.getch()
                if next_char == b'H':  # Up arrow
                    return 'UP'
                elif next_char == b'P':  # Down arrow
                    return 'DOWN'
                elif next_char == b'K':  # Left arrow
                    return 'LEFT'
                elif next_char == b'M':  # Right arrow
                    return 'RIGHT'
            elif len(char) == 1 and 32 <= ord(char) <= 126:  # Printable ASCII
                return char.decode('utf-8')
    except ImportError:
        # Unix/Linux version
        import termios, tty
        if select.select([sys.stdin], [], [], 0) == ([sys.stdin], [], []):
            char = sys.stdin.read(1)
            if char == '\n':
                return '\r'
            elif char == '\x7f':  # Backspace
                return '\b'
            elif char == '\x03':  # Ctrl+C
                return '\x03'
            elif char == '\t':  # Tab key
                return '\t'
            elif char == '\x1b':  # ESC sequence
                # Check for arrow keys
                if select.select([sys.stdin], [], [], 0.01) == ([sys.stdin], [], []):
                    next_char = sys.stdin.read(1)
                    if next_char == '[':
                        if select.select([sys.stdin], [], [], 0.01) == ([sys.stdin], [], []):
                            arrow_char = sys.stdin.read(1)
                            if arrow_char == 'A':  # Up arrow
                                return 'UP'
                            elif arrow_char == 'B':  # Down arrow
                                return 'DOWN'
                            elif arrow_char == 'C':  # Right arrow
                                return 'RIGHT'
                            elif arrow_char == 'D':  # Left arrow
                                return 'LEFT'
            return char
    return None

class CANMonitor:
    def __init__(self, port='COM5', baudrate=115200):
        self.port = port
        self.baudrate = baudrate
        self.ser = None
        self.running = False
        self.devices = {}  # {id: {'angle': float, 'velocity': float, 'status': dict, 'last_seen': timestamp}}
        self.unique_ids = set()
        self.messages = deque(maxlen=100)  # Store last 100 messages
        self.console = Console()
        self.command_history = deque(maxlen=20)
        self.current_command = ""
        self.selected_device_index = 0
        self.pending_status_requests = set()  # Track devices we've sent status commands to
        self.message_count = 0  # Counter for real-time messages
        self.raw_line_count = 0  # Count of any complete serial lines received
        self.raw_byte_count = 0  # Count of all bytes read from serial
        self.last_message_time = time.time()  # Track message timing
        self.last_raw_line_time = time.time()
        self.last_raw_byte_time = time.time()
        self.last_unparsed_log_time = 0.0
        self.last_raw_chunk_log_time = 0.0
        self._rx_buffer = ""
        self.raw_logging = False
        self.raw_log_path = os.path.join(os.path.dirname(__file__), "can_raw.log")
        
        # Scroll tracking
        self.scroll_position = 0  # Current scroll position (0 = bottom, positive = scroll up)
        self.auto_scroll = True  # Whether to auto-scroll to bottom
        self.messages_per_page = 15  # Default, will be updated dynamically based on panel height

    def _update_motion_velocity(self, can_id: int, angle_rad: float, _vel_rad_s: float) -> None:
        """Smoothed velocity (rad/s) from unwrapped angle history only; angle in UI stays raw from firmware."""
        d = self.devices[can_id]
        now = time.time()
        if d.get("_motion_last_t") is not None and (now - d["_motion_last_t"]) > _MOTION_GAP_RESET_S:
            d.pop("angle_history", None)
            d.pop("prev_raw_angle", None)
            d.pop("angle_unwrapped", None)
            d.pop("vel_ema_rad_s", None)
        d["_motion_last_t"] = now

        if "angle_history" not in d:
            d["angle_history"] = deque(maxlen=_ANGLE_HISTORY_MAXLEN)
            d["prev_raw_angle"] = None
            d["angle_unwrapped"] = None
            d["vel_ema_rad_s"] = None

        pa = d["prev_raw_angle"]
        if pa is None:
            d["angle_unwrapped"] = angle_rad
        else:
            delta = angle_rad - pa
            while delta > math.pi:
                delta -= 2.0 * math.pi
            while delta < -math.pi:
                delta += 2.0 * math.pi
            d["angle_unwrapped"] += delta
        d["prev_raw_angle"] = angle_rad
        d["angle_history"].append((now, d["angle_unwrapped"]))

        hist = d["angle_history"]
        while len(hist) >= 2 and (hist[-1][0] - hist[0][0]) > _VELOCITY_WINDOW_S:
            hist.popleft()

        v_window_rad_s = None
        if len(hist) >= 2:
            t0, a0 = hist[0]
            t1, a1 = hist[-1]
            dt = t1 - t0
            if dt >= _VELOCITY_MIN_DT_S:
                v_window_rad_s = (a1 - a0) / dt
            else:
                # ~100 ms between packets → full window < 80 ms until 2nd sample; use last step Δθ/Δt
                t_prev, a_prev = hist[-2]
                t_last, a_last = hist[-1]
                dt_step = t_last - t_prev
                if dt_step > 1e-6:
                    v_window_rad_s = (a_last - a_prev) / dt_step

        if v_window_rad_s is not None:
            if d["vel_ema_rad_s"] is None:
                d["vel_ema_rad_s"] = v_window_rad_s
            else:
                d["vel_ema_rad_s"] = (
                    _VELOCITY_EMA_ALPHA * v_window_rad_s
                    + (1.0 - _VELOCITY_EMA_ALPHA) * d["vel_ema_rad_s"]
                )

        if d["vel_ema_rad_s"] is None:
            d["velocity_display"] = 0.0
        else:
            d["velocity_display"] = d["vel_ema_rad_s"]

    def connect(self):
        """Connect to the serial port"""
        try:
            # Optimize for real-time performance
            self.ser = serial.Serial(
                self.port, 
                self.baudrate, 
                timeout=0.01,  # Avoid excessive line fragmentation at high traffic rates
                write_timeout=0.1,
                inter_byte_timeout=None,  # Disable inter-byte timeout
                exclusive=True  # Exclusive access for better performance
            )
            # Set buffer sizes for better performance
            self.ser.set_buffer_size(rx_size=8192, tx_size=8192)
            self.add_message(f"[green]Connected to {self.port} at {self.baudrate} baud[/green]")
            return True
        except serial.SerialException as e:
            self.add_message(f"[red]Failed to connect: {e}[/red]")
            return False
    
    def disconnect(self):
        """Disconnect from serial port"""
        self.running = False
        if self.ser and self.ser.is_open:
            self.ser.close()
            self.add_message("[yellow]Disconnected[/yellow]")
    
    def add_message(self, message):
        """Add a timestamped message to the display"""
        timestamp = datetime.now().strftime("%H:%M:%S.%f")[:-3]
        self.messages.append(f"[dim]{timestamp}[/dim] {message}")
        
        # Auto-scroll to bottom when new messages arrive
        if self.auto_scroll:
            self.scroll_position = 0

    def _raw_preview(self, data: bytes, max_len: int = 32) -> str:
        """Compact hex+ascii preview for raw serial chunks."""
        if not data:
            return "len=0"
        shown = data[:max_len]
        hex_part = shown.hex(" ").upper()
        ascii_part = "".join(chr(b) if 32 <= b <= 126 else "." for b in shown)
        suffix = " ..." if len(data) > max_len else ""
        return f"len={len(data)} hex=[{hex_part}]{suffix} ascii='{ascii_part}'{suffix}"
    
    def parse_message(self, line):
        """Parse CAN message line like: rcv 56004D 99C4734000000000 E B F r f-1"""
        parts = line.strip().split()
        if len(parts) >= 3 and parts[0].lower() == 'rcv':
            try:
                # Extract ID and data
                can_id = parts[1].upper()
                data_hex = parts[2]
                
                # Convert hex data to bytes
                data_bytes = bytes.fromhex(data_hex)
                
                # Check message type using data[0]
                if len(data_bytes) >= 1:
                    message_type = data_bytes[0]
                    
                    if message_type == 0x01:
                        # Status message
                        if len(data_bytes) >= 4:
                            status_flags = data_bytes[1]
                            driver_ready = data_bytes[2] == 0x01
                            driver_fault = data_bytes[3] == 0x01
                            
                            # Extract individual status flags
                            lock = (status_flags & 0x01) != 0
                            vcc_uvlo = (status_flags & 0x02) != 0
                            vds_p = (status_flags & 0x04) != 0
                            reset = (status_flags & 0x08) != 0
                            thsd = (status_flags & 0x10) != 0
                            
                            # Create or update device info
                            if can_id not in self.devices:
                                self.devices[can_id] = {
                                    'angle': None,
                                    'velocity': None,
                                    'status': None,
                                    'last_seen': time.time()
                                }
                                self.add_message(f"[green]Discovered CAN device {can_id}[/green]")
                            
                            # Update status
                            self.devices[can_id]['status'] = {
                                'lock': lock,
                                'vcc_uvlo': vcc_uvlo,
                                'vds_p': vds_p,
                                'reset': reset,
                                'thsd': thsd,
                                'ready': driver_ready,
                                'fault': driver_fault
                            }
                            self.devices[can_id]['last_seen'] = time.time()
                            self.unique_ids.add(can_id)
                            
                            # Clear pending status request if this was in response to our command
                            if can_id in self.pending_status_requests:
                                self.pending_status_requests.remove(can_id)
                                self.add_message(f"[green]Received status response from {can_id}[/green]")
                            
                            return can_id, None, None, 'status'
                            

                            
                    elif message_type == 0x03:
                        # Initialization status message
                        if len(data_bytes) >= 3:
                            error_flags = data_bytes[1]
                            motor_status = data_bytes[2]
                            
                            error_list = []
                            if error_flags & 0x01:
                                error_list.append("CORDIC")
                            if error_flags & 0x02:
                                error_list.append("DRIVER")
                            if error_flags & 0x04:
                                error_list.append("CURRENT")
                            if error_flags & 0x08:
                                error_list.append("MOTOR")
                            if error_flags & 0x10:
                                error_list.append("FOC")
                            
                            # Interpret motor status
                            motor_status_names = {
                                0x00: "UNINITIALIZED",
                                0x01: "INITIALIZING", 
                                0x02: "UNCALIBRATED",
                                0x03: "CALIBRATING",
                                0x04: "READY",
                                0x08: "ERROR",
                                0x0E: "CALIB_FAILED",
                                0x0F: "INIT_FAILED"
                            }
                            motor_status_name = motor_status_names.get(motor_status, f"UNKNOWN({motor_status:02X})")
                            
                            if error_flags == 0 and motor_status == 0x04:
                                self.add_message(f"[green]CAN {can_id}[/green]: All components initialized successfully, motor READY")
                            elif error_flags == 0:
                                self.add_message(f"[yellow]CAN {can_id}[/yellow]: Components OK, motor status: {motor_status_name}")
                            else:
                                self.add_message(f"[yellow]CAN {can_id}[/yellow]: Init errors: {', '.join(error_list)} (0x{error_flags:02X}), motor: {motor_status_name}")
                            
                            return can_id, None, None, 'init_status'
                            
                    elif message_type == 0x04:
                        # Debug message - now supports up to 63 bytes of debug data
                        if len(data_bytes) >= 2:
                            # Extract debug message from bytes 1 onwards (up to 63 bytes)
                            debug_data = data_bytes[1:]
                            debug_msg = debug_data.decode('ascii', errors='ignore').rstrip('\x00')
                            if debug_msg.strip():  # Only show non-empty messages
                                self.add_message(f"[blue]CAN {can_id}[/blue]: DEBUG: {debug_msg}")
                            return can_id, None, None, 'debug'
                    
                    elif message_type == 0x00:
                        # Motion message (angle/velocity)
                        if len(data_bytes) >= 9:
                            # Extract angle (bytes 1-4) and velocity (bytes 5-8) as little-endian floats
                            angle = struct.unpack('<f', data_bytes[1:5])[0]
                            velocity = struct.unpack('<f', data_bytes[5:9])[0]
                            
                            # Create or update device info
                            if can_id not in self.devices:
                                self.devices[can_id] = {
                                    'angle': None,
                                    'velocity': None,
                                    'status': None,
                                    'last_seen': time.time()
                                }
                                self.add_message(f"[green]Discovered CAN device {can_id}[/green]")
                            
                            # Update motion data (angle/velocity from MCU in radians / rad/s)
                            self.devices[can_id]['angle'] = angle
                            self.devices[can_id]['velocity'] = velocity
                            self.devices[can_id]['last_seen'] = time.time()
                            self.unique_ids.add(can_id)
                            self._update_motion_velocity(can_id, angle, velocity)

                            return can_id, angle, velocity, 'motion'
                    
            except (ValueError, struct.error) as e:
                self.add_message(f"[red]Error parsing message: {e}[/red]")
        
        return None, None, None, None
    
    def monitor_serial(self):
        """Monitor serial port for incoming data"""
        while self.running:
            try:
                if self.ser:
                    raw = self.ser.read(self.ser.in_waiting or 1)
                    if raw:
                        self.raw_byte_count += len(raw)
                        self.last_raw_byte_time = time.time()

                        if self.raw_logging:
                            try:
                                with open(self.raw_log_path, "ab") as f:
                                    f.write(raw)
                            except Exception as e:
                                self.add_message(f"[red]Raw log write error:[/red] {e}")

                            now = time.time()
                            if now - self.last_raw_chunk_log_time >= 0.1:
                                self.last_raw_chunk_log_time = now
                                self.add_message(
                                    f"[magenta]RAW chunk[/magenta] {self._raw_preview(raw)}"
                                )

                        self._rx_buffer += raw.decode('utf-8', errors='ignore')

                        while True:
                            # Accept either CR or LF line terminators (different fdcanusb
                            # firmwares/hosts may emit '\r', '\n', or '\r\n').
                            nl = self._rx_buffer.find('\n')
                            cr = self._rx_buffer.find('\r')
                            if nl < 0 and cr < 0:
                                break
                            if nl < 0:
                                split_idx = cr
                            elif cr < 0:
                                split_idx = nl
                            else:
                                split_idx = min(nl, cr)

                            line = self._rx_buffer[:split_idx]
                            self._rx_buffer = self._rx_buffer[split_idx + 1:]
                            # Consume paired terminator in CRLF / LFCR cases.
                            if self._rx_buffer and self._rx_buffer[0] in ('\r', '\n'):
                                self._rx_buffer = self._rx_buffer[1:]

                            stripped_line = line.strip('\r').strip()
                            if not stripped_line:
                                continue

                            self.raw_line_count += 1
                            self.last_raw_line_time = time.time()

                            can_id, angle, velocity, msg_type = self.parse_message(stripped_line)
                            if can_id:
                                # Update message counter and timing
                                self.message_count += 1
                                self.last_message_time = time.time()
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

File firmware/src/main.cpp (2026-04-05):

#include <Arduino.h>
#ifdef FOC_USE_HARDWARE_TIMER
#include <HardwareTimer.h>
#endif

#include "app/can_init.h"
#include "app/motor_init.h"
#include "commands/commands.h"
#include "debug/can_debug.h"
#include "debug/debug_init.h"
#include "drivers/motor_objects.h"
#include "telemetry/telemetry.h"

#ifndef FOC_LOOP_HZ
#define FOC_LOOP_HZ 10000
#endif

#ifdef FOC_USE_HARDWARE_TIMER
static HardwareTimer s_foc_timer(TIM6);

void foc_timer_isr() {
  motor.loopFOC();
  motor.move();
}
#else
static uint32_t foc_next_us = 0;
#endif

// Per-cycle only: interval = wall time since previous FOC *start* (not cumulative backlog).
// Cooperative loop only (see #ifndef FOC_USE_HARDWARE_TIMER). Hardware-timer FOC does not use this.
static constexpr uint32_t FOC_TIMING_WARN_INTERVAL_OVER_PERIOD_US = 50;  // warn if interval > period + this
// exec*10 > period*FRAC → warn if exec > (FRAC/10)*period. FRAC=10 → warn only if exec exceeds full period.
static constexpr uint32_t FOC_TIMING_WARN_EXEC_FRAC = 10;
static constexpr uint32_t FOC_TIMING_WARN_MIN_INTERVAL_MS = 250;

#ifndef FOC_USE_HARDWARE_TIMER
static void foc_run_cooperative() {
  const uint32_t period_us = 1000000UL / FOC_LOOP_HZ;
  const uint32_t now = micros();
  if ((int32_t)(now - foc_next_us) < (int32_t)period_us) {
    return;
  }
  foc_next_us += period_us;
  const uint32_t foc_t0 = micros();
  static uint32_t last_foc_start_us = 0;
  uint32_t interval_us = 0;
  if (last_foc_start_us != 0) {
    interval_us = foc_t0 - last_foc_start_us;
  }
  last_foc_start_us = foc_t0;
  motor.loopFOC();
  motor.move();
  const uint32_t exec_us = micros() - foc_t0;
  const bool slow_interval =
      interval_us > 0 && interval_us > period_us + FOC_TIMING_WARN_INTERVAL_OVER_PERIOD_US;
  const bool slow_exec = exec_us * 10U > period_us * FOC_TIMING_WARN_EXEC_FRAC;
  if (slow_interval || slow_exec) {
    static uint32_t last_foc_timing_warn_ms = 0;
    const uint32_t ms = millis();
    if (ms - last_foc_timing_warn_ms >= FOC_TIMING_WARN_MIN_INTERVAL_MS) {
      last_foc_timing_warn_ms = ms;
      Serial.print("FOC slow: interval=");
      Serial.print(interval_us);
      Serial.print(" us exec=");
      Serial.print(exec_us);
      Serial.print(" us period=");
      Serial.print(period_us);
      if (slow_interval) {
        Serial.print(" (interval>");
        Serial.print(period_us + FOC_TIMING_WARN_INTERVAL_OVER_PERIOD_US);
        Serial.print(" us)");
      }
      if (slow_exec) {
        Serial.print(" exec>");
        Serial.print(period_us * FOC_TIMING_WARN_EXEC_FRAC / 10U);
        Serial.print(" us");
      }
      Serial.println();
    }
  }
}
#endif  // !FOC_USE_HARDWARE_TIMER

void setup() {
  #ifndef CAN_DEBUG_ENABLED
  Serial.setRx(PA10);
  Serial.setTx(PA9);
  Serial.begin(115200);
  #endif

  can_init();
  debug_init();
  motor_init();

  pinMode(PC2, OUTPUT);
  register_commands();
  // Send final initialization status
  if (init_errors == 0) {
    Serial.println("All components initialized successfully!");
  } else {
    Serial.print("Initialization completed with errors: 0x");
    Serial.println(init_errors, HEX);
  }

  Serial.println("SimpleFOC ready!");
  _delay(1000);

#ifdef FOC_USE_HARDWARE_TIMER
  s_foc_timer.setOverflow(FOC_LOOP_HZ, HERTZ_FORMAT);
  s_foc_timer.attachInterrupt(foc_timer_isr);
  s_foc_timer.resume();
#else
  foc_next_us = micros();
#endif
}

void loop() {
  run_command_loop();
  telemetry_tick();
#ifndef FOC_USE_HARDWARE_TIMER
  foc_run_cooperative();
#endif
}

void SystemClock_Config(void) {
  RCC_OscInitTypeDef RCC_OscInitStruct = {0};
  RCC_ClkInitTypeDef RCC_ClkInitStruct = {0};

  /** Configure the main internal regulator output voltage */
  HAL_PWREx_ControlVoltageScaling(PWR_REGULATOR_VOLTAGE_SCALE1_BOOST);

  /**
   * Initializes the RCC Oscillators according to the specified parameters
   * in the RCC_OscInitTypeDef structure.
   */
  RCC_OscInitStruct.OscillatorType = RCC_OSCILLATORTYPE_HSI;
  RCC_OscInitStruct.HSIState = RCC_HSI_ON;
  RCC_OscInitStruct.HSICalibrationValue = RCC_HSICALIBRATION_DEFAULT;
  RCC_OscInitStruct.PLL.PLLState = RCC_PLL_ON;
  RCC_OscInitStruct.PLL.PLLSource = RCC_PLLSOURCE_HSI;
  RCC_OscInitStruct.PLL.PLLM = RCC_PLLM_DIV4;
  RCC_OscInitStruct.PLL.PLLN = 85;
  RCC_OscInitStruct.PLL.PLLP = RCC_PLLP_DIV8;
  RCC_OscInitStruct.PLL.PLLQ = RCC_PLLQ_DIV2;
  RCC_OscInitStruct.PLL.PLLR = RCC_PLLR_DIV2;
  if (HAL_RCC_OscConfig(&RCC_OscInitStruct) != HAL_OK) {
    Error_Handler();
  }

  /** Initializes the CPU, AHB and APB buses clocks */
  RCC_ClkInitStruct.ClockType = RCC_CLOCKTYPE_HCLK | RCC_CLOCKTYPE_SYSCLK | RCC_CLOCKTYPE_PCLK1 | RCC_CLOCKTYPE_PCLK2;
  RCC_ClkInitStruct.SYSCLKSource = RCC_SYSCLKSOURCE_PLLCLK;
  RCC_ClkInitStruct.AHBCLKDivider = RCC_SYSCLK_DIV1;
  RCC_ClkInitStruct.APB1CLKDivider = RCC_HCLK_DIV1;
  RCC_ClkInitStruct.APB2CLKDivider = RCC_HCLK_DIV1;

  if (HAL_RCC_ClockConfig(&RCC_ClkInitStruct, FLASH_LATENCY_4) != HAL_OK) {
    Error_Handler();
  }
}

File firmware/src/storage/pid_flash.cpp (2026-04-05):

#include "storage/pid_flash.h"

#include "drivers/motor_objects.h"

#include "stm32g4xx_hal_flash.h"
#include "stm32g4xx_hal_flash_ex.h"

// PID storage in flash (last 2KB page of 128KB: 0x0801F800)
namespace {
  constexpr uint32_t PID_FLASH_MAGIC = 0x50494453u;  // "PIDS"
  constexpr uint32_t PID_FLASH_PAGE = 63;
  constexpr uint32_t PID_FLASH_ADDR = 0x08000000u + (PID_FLASH_PAGE * 2048u);
}  // namespace

#pragma pack(push, 1)
struct PidFlashData {
  uint32_t magic;
  float cq_p, cq_i, cq_ramp;
  float cd_p, cd_i, cd_ramp;
  float v_p, v_i, v_d, v_ramp;
  float angle_p, angle_limit;
  float velocity_limit;
};
#pragma pack(pop)

namespace {

bool erase_pid_page_unlocked() {
  FLASH_EraseInitTypeDef erase = {};
  erase.TypeErase = FLASH_TYPEERASE_PAGES;
  erase.Banks = FLASH_BANK_1;
  erase.Page = PID_FLASH_PAGE;
  erase.NbPages = 1;
  uint32_t pageError = 0;
  return HAL_FLASHEx_Erase(&erase, &pageError) == HAL_OK;
}

}  // namespace

bool erase_pid_from_flash() {
  HAL_FLASH_Unlock();
  if (!erase_pid_page_unlocked()) {
    HAL_FLASH_Lock();
    return false;
  }
  HAL_FLASH_Lock();
  return true;
}

bool save_pid_to_flash() {
  PidFlashData data = {};
  data.magic = PID_FLASH_MAGIC;
  data.cq_p = motor.PID_current_q.P;
  data.cq_i = motor.PID_current_q.I;
  data.cq_ramp = motor.PID_current_q.output_ramp;
  data.cd_p = motor.PID_current_d.P;
  data.cd_i = motor.PID_current_d.I;
  data.cd_ramp = motor.PID_current_d.output_ramp;
  data.v_p = motor.PID_velocity.P;
  data.v_i = motor.PID_velocity.I;
  data.v_d = motor.PID_velocity.D;
  data.v_ramp = motor.PID_velocity.output_ramp;
  data.angle_p = motor.P_angle.P;
  data.angle_limit = motor.P_angle.limit;
  data.velocity_limit = motor.velocity_limit;

  HAL_FLASH_Unlock();
  if (!erase_pid_page_unlocked()) {
    HAL_FLASH_Lock();
    return false;
  }
  const uint8_t* src = (const uint8_t*)&data;
  uint32_t addr = PID_FLASH_ADDR;
  size_t len = sizeof(PidFlashData);
  for (size_t i = 0; i < len; i += 8) {
    uint64_t dword = 0;
    for (int j = 0; j < 8 && (i + j) < len; j++) {
      ((uint8_t*)&dword)[j] = src[i + j];
    }
    if (HAL_FLASH_Program(FLASH_TYPEPROGRAM_DOUBLEWORD, addr + i, dword) != HAL_OK) {
      HAL_FLASH_Lock();
      return false;
    }
  }
  HAL_FLASH_Lock();
  return true;
}

bool load_pid_from_flash() {
  const PidFlashData* data = (const PidFlashData*)PID_FLASH_ADDR;
  if (data->magic != PID_FLASH_MAGIC) return false;
  motor.PID_current_q.P = data->cq_p;
  motor.PID_current_q.I = data->cq_i;
  motor.PID_current_q.output_ramp = data->cq_ramp;
  motor.PID_current_d.P = data->cd_p;
  motor.PID_current_d.I = data->cd_i;
  motor.PID_current_d.output_ramp = data->cd_ramp;
  motor.PID_velocity.P = data->v_p;
  motor.PID_velocity.I = data->v_i;
  motor.PID_velocity.D = data->v_d;
  motor.PID_velocity.output_ramp = data->v_ramp;
  motor.P_angle.P = data->angle_p;
  motor.P_angle.limit = data->angle_limit;
  motor.velocity_limit = data->velocity_limit;
  return true;
}

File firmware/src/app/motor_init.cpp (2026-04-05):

#include "app/motor_init.h"

#include <Arduino.h>
#include <cmath>

#include "debug/can_debug.h"
#include "drivers/motor_objects.h"
#include "hal/hw_opamp.h"
#include "storage/pid_flash.h"

#include "utilities/stm32math/STM32G4CORDICTrigFunctions.h"


void motor_init() {
  Serial.println("Initializing CORDIC");
  if (!SimpleFOC_CORDIC_Config()) {
    Serial.println("CORDIC init failed");
    init_errors |= 0x01;
  }

  magnetic_sensor.init(&spi_class);
  motor.linkSensor(&magnetic_sensor);

  driver.voltage_power_supply = 24.0f;
  if (driver.init() == 0) {
    Serial.println("Driver init failed!");
    init_errors |= 0x02;
  } else {
    Serial.println("Driver init success!");
  }

  motor.linkDriver(&driver);

  Serial.print("Driver fault: ");
  Serial.println(driver.isFault() ? "true" : "false");
  if (driver.isFault()) init_errors |= 0x02;

  motor.voltage_sensor_align = 1.5f;

  opamp_init();
  current_sense.linkDriver(&driver);
  if (current_sense.init()) {
    Serial.println("Current sense init success!");
  } else {
    Serial.println("Current sense init failed!");
    init_errors |= 0x04;
  }
  motor.linkCurrentSense(&current_sense);

  motor.controller = MotionControlType::angle;
  motor.torque_controller = TorqueControlType::foc_current;
  motor.foc_modulation = FOCModulationType::SpaceVectorPWM;

  motor.updateVelocityLimit(100.0f);
  motor.updateCurrentLimit(20.0f);

  motor.LPF_current_q.Tf = 0.001;
  motor.LPF_current_d.Tf = 0.001;

  if (load_pid_from_flash()) Serial.println("Loaded PID values from flash.");

  delay(100);
  if (motor.init() == 0) {
    Serial.println("Motor init failed!");
    init_errors |= 0x08;
  } else {
    Serial.println("Motor init success!");
  }

  if (motor.tuneCurrentController(500.0f) == 0) {
    Serial.println("Current controller tuned!");
  } else {
    Serial.println("Current controller tuning failed!");
    init_errors |= 0x10;
  }

  // motor.characteriseMotor(1.0f);
  // Serial.println("Motor characterised!");
  // Serial.print("Motor phase resistance: ");
  // Serial.printf("%f", motor.phase_resistance);
  // Serial.print(" Ω\n");
  // Serial.print("Motor phase inductance: ");
  // Serial.printf("%f", motor.phase_inductance);
  // Serial.print(" H\n");
  // Serial.print("Motor phase KV: ");
  // Serial.printf("%f", motor.KV_rating);
  // Serial.print(" RPM/V\n");
  // return;

  if (motor.initFOC() == 0) {
    Serial.println("Motor FOC init failed!");
    init_errors |= 0x10;
  } else {
    Serial.println("Motor FOC init success!");
  }

  motor.disable();
}

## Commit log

2023-08-05 Slightly cheaper
    [controller-CuBottom.gbr, controller-CuIn1.gbr, controller-CuIn2.gbr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]
2024-02-09 Add code
    [LBM2016T120J.step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]
2024-03-04 Fix op amps, uvlo and thermistor
    [controller.kicad_sch]
2024-07-07 PCB changes
    [controller.kicad_pcb, controller.kicad_sch]
2024-07-07 Motor is turning
2024-07-10 Bit of cleanup and current sensing
2024-11-04 Add schematic
2025-07-10 Current sense working, everything working!
2025-07-13 Reduce clock frequency for reduced power draw, use a library that supports CAN_FD out of the box, add a commander interface to change the update frequency
2025-07-13 Add Status command for CAN, Change PID, I to 0 since it would rapidly go out of control. Add fancy terminal app for controlling motors.
2025-07-21 can_monitor - ability to scroll messages - use can send for extended id
    main.cpp
    - ignore bitrate switching, not needed.
    - add can debug messages for all SimpleFOC serial messages
    - support extended CAN messages
    - reduce current limit
    - motor monitoring through CAN
    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
    [controller.kicad_pcb, controller.kicad_sch]
2025-09-18 - Fix wrong STSPIN pins - Fix can_monitor not showing all messages - Fix printf not working with floats - Fix CAN messages not sending - Reduce motor noise by reducing sensor rate
    [can_monitor.py, main.cpp]
2026-02-18 Working with Moteus Motor
2026-02-18 Working with current control for Moteus Motor
2026-02-22 Add live PID tuning commands and smoother baseline defaults.
    This enables runtime gain adjustments over CAN debug and sets conservative startup parameters that avoid violent oscillation while improving low-speed smoothness.
    [main.cpp]
2026-03-03 - Better PID values - Allowing saving PID values to flash - Allow can_monitor to auto reconnect when CAN device disconnects
2026-03-04 More PID tuning values, hopefully a bit faster and stabler
2026-04-04 Update schematic to 10mohm shunts
    [controller.kicad_sch]
2026-04-04 Reset should just reset the system
    [commands.cpp]
2026-04-05 Add motion velocity estimation to CAN monitor
    - Implemented smoothed velocity calculation based on unwrapped angle history.
    - Introduced constants for velocity window, minimum time delta, and EMA alpha for smoother responses.
    - Updated CAN monitor to display calculated velocity in rad/s.
    - Enhanced motor initialization with improved current sensing and tuning capabilities.
    - Added hardware timer support for FOC loop execution.
    - Enabled CAN debug interface for better diagnostics.
2026-04-05 Enhance PID flash management and motor initialization
    - Added functionality to erase PID data from flash memory.
    - Introduced a new command to trigger PID flash erase via CAN interface.
    - Updated motor initialization to adjust voltage sensor alignment.
    - Improved FOC timing warning constants for better execution monitoring.
2026-05-17 Return rotor after SimpleFOC sensor alignment sweep.
    Add a reverse revolution at the end of alignment so the shaft ends near its starting position.
2026-05-17 Link and upload firmware through OpenBLT on STM32G431.
    Reserve a 20 KB bootloader slot, add OpenBLT linker/startup, PlatformIO envs for ST-Link and CAN upload, and host tools to patch vectors and flash over fdcanusb.
2026-05-17 Use CAN FD BRS in debug TX to match OpenBLT upload.
    So one fdcanusb monitor configuration works for application debug frames and bootloader traffic.
2026-05-17 Refresh KiCad board DRC exclusions and teardrop settings.
    Clear stale clearance exclusions and align teardrop options with current KiCad board settings schema.
2026-05-19 Bring up CAN-FD firmware uploads via OpenBLT + fdcanusb
    Bootloader (submodule -> AeroX2/OpenBLT-STM32 @ deb61737):
    Rewritten as a bare-metal stm32cube PlatformIO port that mirrors the
    upstream Feaser Nucleo-G431 OpenBLT demo. OpenBLT library and STM32G4
    port are compiled directly from the openblt submodule. ~8 KB binary
    (down from ~17 KB on the prior Arduino-framework build).
    OpenBLT (submodule -> AeroX2/openblt @ 36438189):
    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
